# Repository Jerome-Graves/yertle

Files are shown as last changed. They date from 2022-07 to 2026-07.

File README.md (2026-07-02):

new yertle logo

# A 3D Printed Quadrupedal Robot for Locomotion Research

<p align="center" >
 
 
 
 
 
</p>

<p align="center"><b>From a hand-tuned gait to reinforcement-learned locomotion: trained on CPU (PyBullet) and GPU (Isaac Lab), deployed via a sim-to-real bridge and ROS 2.</b></p>

<br>
The robot consists of:

* 4 limbs with 3 degrees of freedom powered by hobby servos, with a leg extension of approximately 20cm.
* A 5000mah battery - 30 minutes of run time (optional). 
* A 9-axis accelerometer/gyro sensor. (optional)
* A current and voltage sensor. (optional)
* A microcontroller (ESP32s) to communicate with Hardware and sensors.
* A single-board computer (RPi4) to compute image, location, ROS and advanced controller algorithms. (optional)
* 1.8 kg

<br>
This robot was inspired by the <a href="https://grabcad.com/library/diy-quadruped-robot-1">Kangal</a>, <a href="https://spotmicroai.readthedocs.io/en/latest/">SpotMicro</a> and <a href="https://github.com/adham-elarabawy/open-quadruped">Open Quadruped</a>. The concept was to have the best parts of all designs and make it compatible with <a href="https://spotmicroai.readthedocs.io/en/latest/">SpotMicro</a> parts.
The current cost of the robot is around £250.
</br>

- - -

<br>

## Robot in action:





giphy

- - -

<br>

## Design:
Click [here](design/README.md) for 3D printer parts, assembly instructions and bill of materials.
<br><br>
Yertle is a  fusion of the leg design of <a href="https://grabcad.com/library/diy-quadruped-robot-1">Kangal</a> and the body of <a href="https://spotmicroai.readthedocs.io/en/latest/">SpotMicro</a>. As such, you can use the control software and electronics from any Kangal or derivative with this robot (with a little modification). Any Modifications for the spot micro shell will also work with this robot. And You can exchange the legs for Kangal's if you want. 
<br>
<br>
I have built a few quadruped robots and there are plenty of interesting leg mechanics to choose from. Overall The Kangal legs do have limitations. Such as their limited range in motion. But they do have the benefit of being extremely light and easy to change. This means I'm not pulling up anything heavy when I'm lifting my leg allowing the servos to be slightly faster when not under load. And I'm less worried about breaking them or putting the robot in a more extreme environment.
<br>


<br>

- - - 
<br>

## Electronics:
Click [here](design/README.md#electronics) for an electronics and wiring explanation.
<br><br>
I'm currently working on a better description of my wiring. I have soldered a custom Hat from my RPi that had all the necessary components. The robot was originally designed to use just the RPi but I found it to be unreliable as it is more complex to reset the device and more prone to corruption. As The ESP32 has WiFi I can debug the device remotely without a complex startup/shut down routine.
<br><br>
If you are familiar with wiring  <a href="https://grabcad.com/library/diy-quadruped-robot-1">Kangal</a> and the body of <a href="https://spotmicroai.readthedocs.io/en/latest/">SpotMicro</a>. You can use the same wiring.

- - -
<br>

## Software:
Click [here](software/README.md) for the software.
<br><br>
The software runs as a host/robot pair over the serial port or UDP over WiFi. The robot firmware controls all sensors and servos, computes the inverse kinematics and applies safety limits. The host side is written in Python 3: it takes the robot's sensor data, generates the motion (the hand-tuned gait in the GUI, or a learned policy from the RL pipelines) and streams it back in real time.
<br><br>
The firmware was written in C++ using Arduino IDE so you can modify it to work on a different microcontroller if you want. 
The Python Control software uses a GUI and can run on anything that has WiFi, a screen and can run Python3, including android devices(not tested).
<br><br>
There is also a ROS 2 package that runs a trained policy as a node, with a closed-loop demo and an Isaac Sim bridge; see [ros2/README.md](ros2/README.md).

- - -
<br>

## Simulation:
Click [here](simulation/README.md) for simulation tools.<br><br>
There is a simulation built into the python software. It enables you to test movement with the controller without a robot. 
<br><br>


<br><br>

Here is another simulation example from Carter James using Unity.
<br><br> 
IMAGE ALT TEXT HERE (https://www.youtube.com/watch?v=7LgCC4D3Wlk)
- - -
<br>

## Learned locomotion (reinforcement learning):
Click [here](learning/README.md) for the RL locomotion pipeline.<br><br>
Alongside the hand-tuned sinusoidal gait, Yertle now has a reinforcement-learning
environment for training a walking policy in simulation and transferring it to
the physical robot. It wraps the same URDF in a Gymnasium environment
(PyBullet backend), trains with PPO, and uses domain randomisation (mass,
friction, sensor noise, pushes) to close the sim-to-real gap. The trained
policy outputs joint targets on the existing UDP command path, so no firmware
change is needed to deploy it.

```bash
pip install -r requirements.txt -r learning/requirements-rl.txt
python -m learning.smoke_test          # check the environment
python -m learning.train --timesteps 3000000 --n-envs 8
```

- - -
<br>

## GPU locomotion with NVIDIA Isaac Lab:
Click [here](isaac_lab/README.md) for the Isaac Lab pipeline.<br><br>
The same robot is also trained on **NVIDIA Isaac Lab** (Isaac Sim 5.1 + PhysX),
the industry-standard stack for legged-robot RL. The URDF (with firmware joint
limits and actuator caps) is converted to USD and dropped into Isaac Lab's
velocity-tracking locomotion task, then trained with `rsl_rl` PPO across
**4096 parallel environments** on a single RTX GPU. A walking policy converges
in about ten minutes (~80,000 simulation steps per second). The pipeline also
includes a **rough-terrain task** (procedural terrain plus a height scanner) and
**teacher-student distillation** that removes the privileged base-velocity
observation with no loss of performance, giving a policy that runs from
on-board sensors only.

<p align="center">
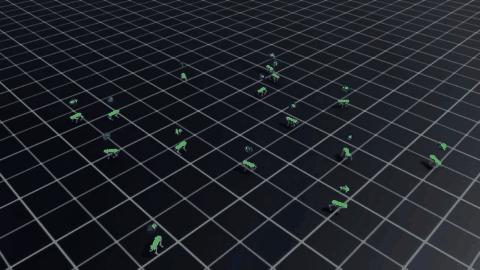
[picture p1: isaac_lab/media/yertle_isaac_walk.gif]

<br>
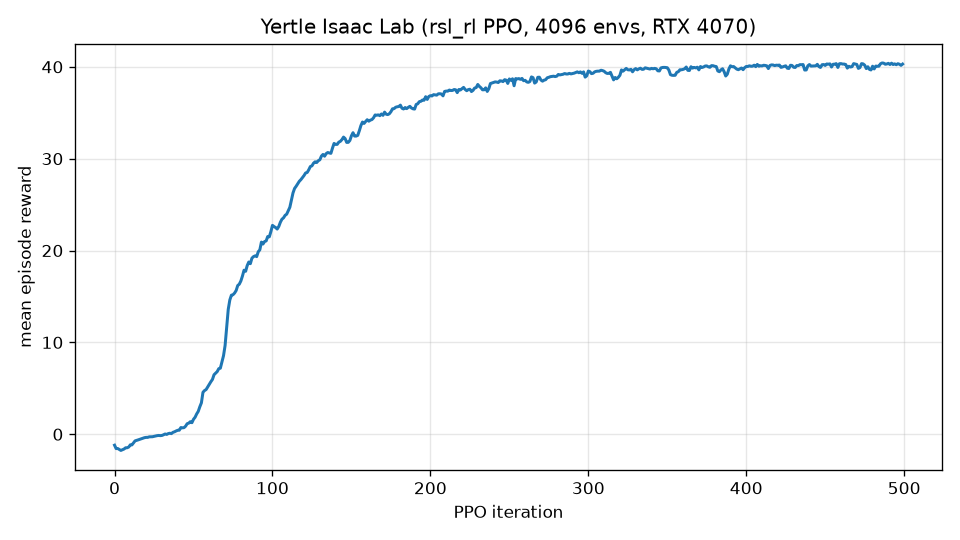
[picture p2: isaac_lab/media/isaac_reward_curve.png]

</p>

```bash
# in the Isaac Sim python env, from the repo root
python isaac_lab/train.py --task flat --headless --num_envs 4096 --max_iterations 1500
python isaac_lab/train.py --task rough --headless --num_envs 4096 --max_iterations 1000
python isaac_lab/play.py --task flat --checkpoint <model.pt> --num_envs 16 --video
python isaac_lab/distill.py --headless --teacher <model.pt>
```

- - -
<br>

## Repository structure

```
design/        3D-printed parts, assembly guide and bill of materials
simulation/    URDF model (valid inertials, firmware joint limits) and meshes
software/
    ESP32/     Robot firmware (C++, Arduino / FreeRTOS)
    yertle_ui/  Python control GUI: IK, PID balance, gait, PyBullet simulation
learning/      RL locomotion, CPU (Gymnasium + PyBullet + PPO) and sim-to-real bridge
isaac_lab/     RL locomotion, GPU (Isaac Lab + rsl_rl): flat, rough terrain,
               distillation, Isaac ROS 2 bridge
ros2/          ROS 2 package + closed-loop demo for a trained policy
paper/         Technical report (LaTeX; built PDF included)
media/         Demo montage video and GIF
requirements.txt, pyproject.toml   Python dependencies
```

- - -
<br>

## Getting started (control software)

Requires Python 3.9 or newer.

```bash
git clone https://github.com/Jerome-Graves/yertle.git
cd yertle
pip install -r requirements.txt
python software/yertle_ui/yertle_ui.py
```

On Debian/Ubuntu, tkinter is a separate system package: `sudo apt install python3-tk`.

You do not need the physical robot to try it. Launch the GUI, press **Start Simulation** to open the PyBullet digital twin, then drive it with the arrow keys.

**Building the firmware:** open `software/ESP32/firmware/firmware.ino` in the Arduino IDE with the ESP32 board package installed, along with the `FaBoPWM_PCA9685` and `MPU9250` libraries. WiFi credentials and IP addresses are set near the top of `yertle_lib.cpp`.

- - -
<br>

## Technical report

A six-page write-up of the whole project (system, both RL pipelines, results on
flat and rough terrain, distillation, deployment and ROS 2 integration, and the
engineering lessons) is in [paper/yertle_report.pdf](paper/yertle_report.pdf).

- - -
<br>

## To Do

*  Deploy the distilled policy to the physical robot and close the sim-to-real loop
*  Identify a stable measured actuator model from bench data

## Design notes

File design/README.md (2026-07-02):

new yertle logo
<p style=" display: block;margin-left: auto;margin-right: auto;text-align:center;">
    
</p>


# Table of Contents 
<p  style=" display: block;margin-left: auto;margin-right: auto;text-align:center;">
<a href="#3d-printed-parts">3D Printed Parts</a><br>
<a href="#bill-of-materials">B.O.M (Bill of Materials)</a><br>
<a href="#electronics">Electronics</a><br>
<a href="#assembly">Assembly</a><br>
</p>

- - -

<br>

# 3D Printed Parts 
Yertle can be 3D printed with PLA or ABS. You will need a printer with a build plate of at least 150x150mm. It took me roughly 2 weeks (5-10 hours a day) to print all the parts on my <b>Ender 3 Pro</b>. Most of the parts are compatible with the original SpotMicro parts.

<br>

### Shell:

| Item | Quantity | Link | Notes |
| --- | --- | --- | --- |
| Top Shell | 1 | [link](STL/Shell/Top_Shell.stl) | print in secondary colour  |
| Bottom Shell | 1 | [link](STL/Shell/Bottom_Shell.stl) |print in secondary colour |
| Front Shell | 1 | [link](STL/Shell/Front_Shell.stl) |print in secondary colour  |
| Back Shell | 1 | [link](STL/Shell/Back_Shell.stl) | print in secondary colour |

<br>

### Body Frame:
| Item | Quantity | Link | Notes |
| --- | --- | --- | --- |
| Inner Shoulder Frame | 2 | [link](STL/Frame/Inner_Shoulder_Frame.stl) |  no supports|
| Outer Shoulder Frame | 2 | [link](STL/Frame/Outer_Shoulder_Frame.stl) |  no supports|
| Upper Shoulder Frame | 2 | [link](STL/Frame/Upper_Shoulder_Frame.stl) |  no supports|
| Lower Shoulder Frame | 2 | [link](STL/Frame/Lower_Shoulder_Frame.stl) |  no supports|
| Left Servo Mount | 2 | [link](STL/Frame/Left_Servo_Mount.stl) |  no supports|
| Right Servo Mount | 2 | [link](STL/Frame/Right_Servo_Mount.stl) |  no supports|
| Servo Mount Top Bracket  | 4 | [link](STL/Frame/Servo_Mount_Top_Bracket.stl) |  no supports|
| Side Body beam | 2 | [link](STL/Frame/Side_Body_Beam.stl) |  no supports|
| Electronics Mounting Plate | 1 | [link](STL/Frame/Electronics_Mounting_Plate.stl) |  no supports|

<br>

### Legs:
| Item | Quantity | Link | Notes |
| --- | --- | --- | --- |
| Inner Tibia | 4 | [link](STL/Legs/Inner_Tibia.stl) | |
| Outer Tibia | 4 | [link](STL/Legs/Outer_Tibia.stl) | |
| Femur | 4 | [link](STL/Legs/Femur.stl) | |
| Femur Servo Connector | 4 | [link](STL/Legs/Femur_Servo_Connector.stl) | high infill|
| Left Shoulder | 2 | [link](STL/Legs/Left_Shoulder.stl) |  print in secondary colour |
| Right Shoulder | 2 | [link](STL/Legs/Right_Shoulder.stl) |  print in secondary colour |
| Short Link | 4 | [link](STL/Legs/Short_Link.stl) | |
| Long Link | 4 | [link](STL/Legs/Long_Link.stl) |  |

- - -

<br>
<br>

# Bill of Materials:
| Item | Quantity | Cost | Link | Notes |
| --- | --- | --- | --- | --- |
| PLA | 1Kg | £19 | -- | This can also be ABS or PETG. |
| SPT Servo SPT5435LV-180W 35KG | 12 | £162.36 | [link](https://uk.banggood.com/SPT-Servo-SPT5435LV-180W-35KG-Large-Torque-Waterproof-Metal-Gear-Digital-Servo-For-RC-Robot-RC-Car-p-1577514.html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) | They need to be >= 15Kg/cm.|
| M3 Screws, Nuts and washers | x100 | £10 | [link](https://amzn.eu/d/dV1QDNL) | |
| MPU9250 | 1 | £5 | [link](https://www.aliexpress.com/item/1005004573086760.html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) | optional, you can use a different IMU if needed |
| ESP32s | 1 | £5 | [link](https://www.google.com/search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) | |
| (Raspberry Pi 4B) | 1 | £50 | [link](https://www.aliexpress.com/item/1005003952938315.html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) | This is optional, The robot can use a remote device instead.  |
| PCA9685 Servo Driver | 1 | £4 | [link](https://www.aliexpress.com/item/32469378576.html) |  |
| 7.4V 2S 5000mAh 50C LiPo Battery | 1 | £30 | [link](https://amzn.eu/d/aaM0lUO) | this can be smaller if you want less weight/cost |
| SBEC 6V 20A | 1 | £20 | [link](https://hobbyking.com/en_us/yep-20a-hv-2-12s-sbec-w-selectable-voltage-output.html) | |
| Miniature Ball Bearings 5x16x5mm | 4 | £3 | [link](https://www.ebay.co.uk/itm/394185642290) | |
|  Deep Groove Ball Bearings 25x37x7mm | 4 | £9 | [link](https://www.ebay.co.uk/itm/124120979478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) |  |
|  RS PRO Miniature Ball Bearing 3x13X5mm  | 8 | £9 | [link](https://www.ebay.co.uk/itm/304258710252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) |  |
| 25T Metal Servo Circular Horn | 4 | £5 | [link](https://amzn.eu/d/hwdEX03) |  |
| 25T Metal Servo Arm Horn  | 4 | £5 | [link](https://www.amazon.co.uk/N-Aluminum-Clamping-Steering-Crawler/dp/B08V4NP2JT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) |  |
| Sleeve Bearing 3mm Bore x 5mm OD x 5mm | 32 | £15 | [link](https://amzn.eu/d/bPWGEY8) |  |
<br>

<br>
<br>

# Electronics

Yertle is controlled by an ESP-32s microcontroller and a Raspberry Pi 4 Single board computer. The robot can operate with just the ESP but will require a computer or phone with WiFi capable of running python3. The flow diagram shows the general electronic connections and wiring. 
The current and voltage sensors are optional.

Yertle Diagram flow

<br>
<br>

# Assembly

<br>

## Part1:
Connect and wire electronics to the mounting plate. You can use cable ties to hold the SBEC and battery. I normally connect the esp on top of the pi by soldering a custom Pi hat board that also mounts the IMU.



<br>

## Part2:
Construct the frame with inner servos and electronics.


<br>

## Part3:
Construct the legs.



<br>

## Part4:
Connect electronics and zero the servos (before connecting legs).



<br>

## Part5:
Connect legs and Shell.



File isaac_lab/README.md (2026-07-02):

# Yertle on Isaac Lab (GPU RL)

A second, GPU-accelerated locomotion pipeline for Yertle built on **NVIDIA Isaac
Lab** (Isaac Sim 5.1 + PhysX). It trains a velocity-tracking walking policy with
thousands of parallel environments on an RTX GPU, complementing the CPU
[PyBullet pipeline](../learning/README.md).

```
isaac_lab/
    yertle_cfg.py           Articulation config (spawns the converted USD, leg actuators)
    flat_env_cfg.py         Flat-terrain velocity task (inherits Isaac Lab's locomotion env)
    rough_env_cfg.py        Rough-terrain task (procedural terrain + height scanner)
    rsl_rl_ppo_cfg.py       PPO runner configs (flat and rough)
    distill_env_cfg.py      Distillation env (student obs group without privileged terms)
    rsl_rl_distill_cfg.py   Teacher-student distillation runner config
    train.py                Train on GPU (--task flat|rough)
    play.py                 Roll out / record a trained policy (--task flat|rough)
    distill.py              Distill the trained teacher into a deployable student
    ros2_bridge.py          Expose the Isaac simulation on ROS 2 topics (bidirectional)
```

The environment inherits Isaac Lab's proven `LocomotionVelocityRoughEnvCfg` (the
task that trains ANYmal / Unitree Go2 to walk) and swaps in the Yertle robot,
remapping body names to Yertle's (`base_link`, feet = `*_shin`).

## Prerequisites

Isaac Sim needs Python 3.10/3.11 and an NVIDIA RTX GPU. Create a dedicated
Python 3.11 virtual environment (referred to as `<isaac_venv>` below) and
install per Isaac Lab's pip instructions:

```bash
pip install -U torch==2.7.0 torchvision==0.22.0 --index-url https://download.pytorch.org/whl/cu128
pip install "isaaclab[isaacsim,all]==2.3.2.post1" --extra-index-url https://pypi.nvidia.com
```

## 1. Convert the robot model (URDF -> USD)

```bash
python IsaacLab/scripts/tools/convert_urdf.py \
    simulation/yertle.urdf simulation/usd/yertle.usd --merge-joints --headless
```

This is already done; the USD lives in `simulation/usd/`.

## 2. Train (GPU)

Run from the repo root with the Isaac Sim python and the EULA accepted. Run the
scripts as plain files (not `-m`): on Windows, importing heavy libraries before
the Kit app launches is what avoids the DLL-conflict crash, and the scripts
handle that ordering themselves.

```bat
set OMNI_KIT_ACCEPT_EULA=YES
<isaac_venv>\Scripts\python.exe isaac_lab\train.py --task flat --headless --num_envs 4096 --max_iterations 1500
<isaac_venv>\Scripts\python.exe isaac_lab\train.py --task rough --headless --num_envs 4096 --max_iterations 1000
```

Logs and checkpoints: `isaac_lab/runs/<experiment>/<timestamp>/`. Watch with
`tensorboard --logdir isaac_lab/runs`.

## 3. Play / record

```bat
<isaac_venv>\Scripts\python.exe isaac_lab\play.py --task flat --checkpoint <path> --num_envs 16 --video
```

## 4. Distill to a deployable policy

The flat policy observes the base linear velocity, which the real robot cannot
measure. Distillation trains a student from a deployable observation set (no
base linear velocity, no height scan) to imitate the trained teacher:

```bat
<isaac_venv>\Scripts\python.exe isaac_lab\distill.py --headless --teacher isaac_lab\runs\yertle_flat\<run>\model_1499.pt
```

Result on this robot: student mean reward 40.4 against the teacher's 40.5, with
an imitation loss of about 1e-3.

## 5. ROS 2 bridge

`ros2_bridge.py` publishes `/joint_states` and `/clock` and subscribes to
`/joint_command`, exposing the GPU simulation to any ROS 2 stack. Validated
bidirectionally; see [ros2/README.md](../ros2/README.md) for the demo and the
Windows setup notes.

## Notes

- The default standing pose and actuator gains in `yertle_cfg.py` are starting
  points carried over from the PyBullet env; tune if the robot spawns collapsed.
- The URDF now carries firmware-derived joint limits (revolute joints) and the
  actuator enforces effort/velocity caps, so learned behavior stays within what
  the hardware can execute. An explicit DC-motor actuator model was evaluated
  and rejected as underdamped at these gains (see the comment in
  `yertle_cfg.py` and the technical report).
- A quick model sanity check after any URDF/actuator change: command the
  standing pose with zero action and confirm the base height holds steady.

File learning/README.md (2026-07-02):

# Learned locomotion for Yertle

Reinforcement-learning pipeline that replaces the hand-tuned sinusoidal gait
with a **policy trained in simulation** and intended for **sim-to-real**
transfer onto the physical robot.

The environment reuses the existing `simulation/yertle.urdf`, so the learned
controller drives the same 12-DOF machine the rest of the repository builds.

```
learning/
    yertle_env.py         Gymnasium environment (PyBullet backend)
    train.py              PPO training (stable-baselines3)
    enjoy.py              Roll out / render a trained policy
    deploy.py             Sim-to-real bridge (see also ../ros2)
    record_video.py       Save an mp4/gif of a trained policy
    plot_progress.py      Reward curve PNG from a training log
    smoke_test.py         Fast env check, no RL deps required
    requirements-rl.txt   RL dependencies (gymnasium, sb3, torch, ...)
```

## Install

```bash
pip install -r requirements.txt -r learning/requirements-rl.txt
```

`smoke_test.py` only needs `pybullet`, `gymnasium` and `numpy` (already in the
base `requirements.txt`), so you can check the environment before pulling in
Torch.

## Quick start

```bash
# 1. Sanity-check the environment (random actions, a few seconds)
python -m learning.smoke_test

# 2. Short training smoke run
python -m learning.train --timesteps 20000 --n-envs 2

# 3. A real run (minutes-to-hours depending on hardware)
python -m learning.train --timesteps 3000000 --n-envs 8

# 4. Watch the result
python -m learning.enjoy --policy learning/runs/ppo_yertle/policy.zip

# 5. Produce demo artifacts
python -m learning.record_video --policy learning/runs/ppo_yertle/policy.zip --seconds 8
python -m learning.plot_progress --log learning/runs/train_ppo_yertle.log
```

TensorBoard: `tensorboard --logdir learning/runs`.

## Environment design

**Action** (12): joint-angle residuals around a fixed standing pose, tracked by
a position controller. This matches how the real robot is commanded (joint
angles over WiFi/serial), which keeps the sim-to-real gap small.

**Observation** (48): base linear velocity, base angular velocity, projected
gravity (an IMU-style "which way is down" signal), the velocity command, and
joint positions / velocities / previous action.

**Reward**: track a commanded body velocity (forward, lateral, yaw) while
staying upright and at height, with penalties on energy, action rate,
orientation and falling.

**Physics sanitation.** The shipped URDF was authored for visualisation and its
inertia tensors are not physically valid, so the raw model diverges when
simulated freely. On load the environment overrides each link's inertia with a
stable estimate from its mass and sets foot friction. Turning a display model
into a trainable dynamics model is part of the work here.

**Domain randomisation** (per episode): base mass, foot friction, observation
noise and random pushes. This is the main lever for surviving transfer to
hardware.

## Sim-to-real plan

The policy is a small MLP, so deployment is light:

1. Export the trained weights (the residual-around-stance action design makes
   the mapping to servo angles direct).
2. Run inference at the control rate on the Raspberry Pi (or a laptop) using
   the IMU + commanded joint state to build the observation.
3. Stream the resulting joint targets to the ESP32 over the existing UDP path
   (`f`/`a` command strings in `software/ESP32/firmware`).

The privileged observation term (base linear velocity) is handled by
teacher-student distillation in the GPU pipeline
([isaac_lab/distill.py](../isaac_lab/distill.py)): the student policy matches
the teacher with that term removed, so deployment needs only on-board signals.

## Status

Complete and validated end to end: the environment trains, and the included
full run (3M steps) produced a walking policy that tracks commanded forward
speeds of about 0.2 m/s. The same policy also drives the robot over live ROS 2
topics in the closed-loop demo (`ros2/demo_ros2_loop.py`). For a faster, more
polished gait, see the GPU pipeline in [isaac_lab/](../isaac_lab/README.md),
which trains in minutes and adds rough terrain and distillation.

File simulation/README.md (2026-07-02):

new yertle logo

# Simulation
 
 



<!--
# Table of Contents 
<p  style=" display: block;margin-left: auto;margin-right: auto;text-align:center;">
<a href="#wifi">WiFi</a><br>
<a href="#Robot Firmware">Firmware</a><br>
<a href="#Control Software">Control Software</a><br>
<a href="#ros">ROS</a><br>

</p>
-->

- - -
<br><br>
The robot model is the URDF file [yertle.urdf](yertle.urdf). It is
simulation-ready: the inertia tensors are physically valid, the twelve leg
joints are revolute with firmware-derived limits, and the actuators carry
effort and velocity caps, so the same model works in PyBullet and in
PhysX-based simulators.

For NVIDIA Isaac Sim / Isaac Lab, convert it to USD with Isaac Lab's importer
(the generated `usd/` directory is regenerable and not committed):

```
python IsaacLab/scripts/tools/convert_urdf.py simulation/yertle.urdf simulation/usd/yertle.usd --merge-joints --headless
```
<br>

There is a pyBullet simulation in the python control software, and the RL
pipelines ([learning/](../learning/README.md),
[isaac_lab/](../isaac_lab/README.md)) build their training environments from
this same model.
<br><br>

<br><br>
It creates a digital twin of the robot. You can control it with the UI. To move the robot around using the Keyboard direction keys. 
<br><br>

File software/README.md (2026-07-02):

new yertle logo
<p>
 
 
 
</p>


# Table of Contents 
<p  style=" display: block;margin-left: auto;margin-right: auto;text-align:center;">
<a href="#wifi">WiFi</a><br>
<a href="#Robot Firmware">Firmware</a><br>
<a href="#Control Software">Control Software</a><br>
<a href="#ros">ROS</a><br>

</p>

- - -
<br><br>
There are 2 options for controlling the robot. You can run The python GUI script from a remote device and connect to the robot via WiFi (recommended) or use a remote desktop application to run the script from the RPi.
<br><br>

# WiFi

There are a few references to IP addresses in the code. You will have to modify them in the python and the .ino file.  I am working on making this easier.
<br><br>
The robot will want to connect to WiFi when it starts.
The default login details are: <br>
* SSID : <b>dog-net</b>

* PASSWORD: <b>dognet123</b>

You can change these near the top of the <b>yertle_lib.cpp</b> file.
<br><br>

</p>

- - -

<br>

# Firmware
This was written in <b>C++</b> using the <b>Arduino IDE</b>. It uses <b>FreeRtos</b> to separate tasks to different cores of the ESP32.
One task deals with WiFi and serial communication, while the other deals with I2C communication and inverse kinematics calculations. [Link](ESP32/firmware/firmware.ino)

- - -

<br>

# Control Software
This was written in <b>Python3</b> and uses the <b>tkinter</b> library to generate a GUI to control the robot. It connects to the robot through either <b>Wifi</b> or <b>serial</b> communication. The robot sends sensor information and the control software generates the feet's position and sends it back to the robot in real-time.



## Configuring IMU

The IMU needs to be initially calibrated. These settings are saved in an <b>.ini</b> and reused when the robot is restarted.
- - -
<br>

## Zeroing servos
You can use this GUI to Zero servos before fully constructing robot.
* Use the servo control tab bo visual center servos 
* Press the Get PWM button to get the current PWM values and use these in <b>.ino</b> file to set <b>servo offsets</b>.

<br>

# ROS 2
Done. A ROS 2 package (`ros2/yertle_rl`) runs a trained locomotion policy as a
node (subscribes `/cmd_vel` and `/imu/data`, publishes 12 joint targets), with a
closed-loop walking demo over live topics and a bidirectional Isaac Sim bridge.
See [ros2/README.md](../ros2/README.md).
- - -

<br>

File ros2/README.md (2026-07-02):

# ROS 2 integration

A ROS 2 node that runs the learned locomotion policy on Yertle.

```
ros2/
    yertle_rl/                 ament_python package
        yertle_rl/policy_node.py   the node (thin wrapper over learning/deploy.py)
        package.xml, setup.py      package metadata
```

## What the node does

`policy_node` subscribes to a velocity command and IMU (and optionally joint
feedback), runs the trained policy at a fixed control rate, and publishes 12
joint targets:

| Direction | Topic | Type |
|---|---|---|
| sub | `/cmd_vel` | `geometry_msgs/Twist` |
| sub | `/imu/data` | `sensor_msgs/Imu` |
| sub | `/joint_states` (optional) | `sensor_msgs/JointState` |
| pub | `/joint_commands` | `std_msgs/Float64MultiArray` (12 targets, rad) |

The heavy lifting (observation assembly, policy inference, joint limiting) lives
in [`learning/deploy.py`](../learning/deploy.py), which is validated by the
simulation self-check (`python -m learning.deploy --check`). The node is a thin
ROS wrapper around that same tested core.

## Status

Built and run on **ROS 2 Humble**: the package compiles with `colcon`, and the
node runs live — publishing a `/cmd_vel` and an `/imu` produces `/joint_commands`
(12 joint targets) from the policy. It was validated on Windows with no WSL, via
RoboStack (ROS 2 as conda packages), which is the quickest way to run it here.

**Closed-loop demo.** `demo_ros2_loop.py` runs the full control loop over ROS 2
topics: a PyBullet simulation node publishes `/joint_states` and `/imu/data` and
applies `/joint_commands`, while `policy_node` runs the trained policy against a
`/cmd_vel` command. With the trained PyBullet policy the robot walks
(~0.5 m of base travel in 8 s at a 0.25 m/s command):

```bash
conda run -n ros2 python ros2/demo_ros2_loop.py --policy learning/runs/ppo_walk2/policy.zip
```

**Isaac Sim bridge (validated, bidirectional).** `isaac_lab/ros2_bridge.py`
exposes the GPU simulation on ROS 2 topics through Isaac's
`isaacsim.ros2.bridge` OmniGraph extension: it publishes `/joint_states` and
`/clock` and subscribes to `/joint_command` (sensor_msgs/JointState). This was
verified end to end across two separate ROS 2 installations: the RoboStack env
receives all 12 Yertle joints on `/joint_states`, and commanding
`/joint_command` from RoboStack moves the joints in Isaac (thigh commanded to
-1.2 rad, tracked exactly). Two Windows notes, handled by the launcher: the
bridge needs `ROS_DISTRO=humble` and Isaac's bundled
`isaacsim.ros2.bridge\humble\lib` on `PATH` before startup, and the sim loop
must step with an app update (`sim.step(render=True)`) or the OmniGraph
publishers never tick.

## Build and run — Linux (Ubuntu, ROS 2 Humble/Jazzy)

```bash
# from a sourced ROS 2 workspace
mkdir -p ~/yertle_ws/src && cd ~/yertle_ws/src
ln -s /path/to/yertle/ros2/yertle_rl .
cd ~/yertle_ws
colcon build --packages-select yertle_rl
source install/setup.bash

# the node imports the repo's `learning` package; put the repo root on PYTHONPATH
PYTHONPATH=/path/to/yertle ros2 run yertle_rl policy_node \
    --ros-args -p policy_path:=/path/to/policy.zip
```

## Build and run — Windows (no WSL, via RoboStack)

```bat
:: install Miniforge, then create a ROS 2 env
conda create -y -n ros2 -c conda-forge -c robostack-staging ros-humble-ros-base colcon-common-extensions
conda run -n ros2 pip install pybullet gymnasium

:: build (keep outputs outside the repo)
cd yertle\ros2
conda run -n ros2 colcon build --base-paths . --build-base %USERPROFILE%\ros_ws\build --install-base %USERPROFILE%\ros_ws\install
```

Before building, set your maintainer email in `package.xml` and `setup.py`
(currently a placeholder). The node runs with no `policy_path` too, in which
case it outputs the standing pose (handy for a plumbing check).

## Wiring it to the robot

`/joint_commands` (target joint angles in radians) can be consumed by either:

* a `ros2_control` forward position controller in a Gazebo/RViz simulation, or
* a small relay that reuses `learning.deploy.servo_command_string` to forward
  the targets to the ESP32 firmware over UDP.

The IMU and joint feedback plumbing mirrors the sim-to-real notes in
[`learning/README.md`](../learning/README.md): base linear velocity is a
privileged term and is zero-filled on hardware.

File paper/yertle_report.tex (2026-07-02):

\documentclass[11pt]{article}

% Build with XeLaTeX + Biber (see build.ps1).
\usepackage{fontspec}
\usepackage[a4paper,margin=25mm]{geometry}
\usepackage{graphicx}
\usepackage{booktabs}
\usepackage{amsmath}
\usepackage{siunitx}
\usepackage{xcolor}
\usepackage{caption}
\usepackage[colorlinks=true,linkcolor=black,citecolor=blue,urlcolor=blue]{hyperref}
\usepackage[backend=biber,style=numeric,sorting=none]{biblatex}
\addbibresource{references.bib}

\captionsetup{font=small,labelfont=bf}
\graphicspath{{figures/}}

\title{\textbf{Yertle: Learned Locomotion for a Low-Cost 3D-Printed Quadruped}\\
\large From a Hand-Tuned Gait to Reinforcement Learning and Sim-to-Real}
\author{Jerome Graves}
\date{2026}

\begin{document}
\maketitle

\begin{abstract}
\noindent
Yertle is an open-source, 3D-printed, twelve degree-of-freedom quadruped built
from hobby servos at a hardware cost of around \pounds 250. This report describes
its progression from a hand-tuned sinusoidal gait to learned locomotion trained
with deep reinforcement learning, together with a path to deployment on the
physical robot. Two independent training pipelines are presented: a CPU pipeline
using PyBullet and Proximal Policy Optimization, and a GPU pipeline using NVIDIA
Isaac Lab with thousands of parallel environments. The Isaac Lab pipeline learns
a velocity-tracking walking policy in about ten minutes on a single consumer GPU,
reaching full-length episodes (the robot does not fall) while tracking commanded
body velocities. A sim-to-real deployment bridge and a ROS 2 node are described
that turn a trained policy into joint commands for the on-board microcontroller.
The report also documents the practical engineering that such a project requires,
including physics-model repair, reward shaping, and a set of Windows-specific
issues encountered when running the simulators.
\end{abstract}

\section{Introduction}
Legged locomotion has moved decisively toward learning-based control. Policies
trained in simulation and transferred to hardware now walk, run, and recover on
real quadrupeds \cite{hwangbo2019anymal}, and the availability of massively
parallel GPU simulation has reduced training time from days to
minutes \cite{rudin2022minutes}. Most demonstrations, however, use expensive
research platforms. This work applies the same modern stack to \emph{Yertle}, a
cheap, printable quadruped, and takes it end to end: from a mechanism and
firmware through two reinforcement-learning pipelines to a deployable controller
and a ROS 2 interface.

The contributions are practical rather than novel in method. They are: (i) a
clean, reproducible reinforcement-learning environment for a low-cost quadruped,
provided in both a CPU (PyBullet) and a GPU (Isaac Lab) form; (ii) a trained
velocity-tracking walking policy and the artifacts to reproduce it; (iii) a
sim-to-real bridge and a ROS 2 node that connect the learned policy to the
existing firmware; and (iv) an honest account of the engineering obstacles, which
are usually omitted from polished results but dominate the real effort.

\section{System Overview}
Yertle consists of four legs, each with three degrees of freedom driven by hobby
servos, giving a leg extension of roughly \SI{20}{\centi\meter} and a total mass
near \SI{1.8}{\kilogram}. An ESP32 microcontroller running FreeRTOS handles the
servo bus (through a PCA9685 driver), reads a nine-axis inertial measurement
unit, and communicates over WiFi or serial. One core computes inverse kinematics
and drives the servos; the other handles communication. A host computer sends
either joint angles or Cartesian foot targets, and the firmware executes them.
The original control software is a Python GUI that generates a sinusoidal trot by
hand. The work described here replaces that hand-tuned gait with a learned policy.

\section{Simulation Model}
Both pipelines share the same kinematic description, a URDF exported from the CAD
model. Preparing this model for physics simulation required two fixes that are
representative of the practical work involved.

\paragraph{Inertia.} The exported URDF specified physically invalid inertia
tensors: zero inertia on the base link and, on the leg links, off-diagonal terms
equal to the diagonal terms. A valid rigid-body inertia tensor must be symmetric
positive-definite. PyBullet tolerates the invalid values by silently
recomputing, but the PhysX engine used by Isaac Lab rejects them for articulated
bodies. Each tensor was replaced with a stable, mass-scaled diagonal estimate.

\paragraph{Mesh naming.} Four mesh files contained spaces in their names. This is
harmless for PyBullet but illegal in the prim-path syntax used by Universal Scene
Description (USD), so the conversion to USD failed until the files were renamed.

For the GPU pipeline the corrected URDF is converted to USD with Isaac Lab's
importer, merging the fixed base joint and producing an articulation with a
\texttt{base\_link} root and twelve revolute joints.

\section{Method}
\subsection{Reinforcement-learning formulation}
Locomotion is posed as velocity-command tracking. At each control step the policy
observes the base linear and angular velocity, a projected-gravity vector (which
is an inertial-measurement-style estimate of the down direction), the commanded
body velocity, the joint positions and velocities, and the previous action. The
action is a set of twelve target joint angles, applied as offsets around a fixed
standing pose and tracked by a position controller. This choice mirrors the real
robot, which is commanded with joint angles, and keeps the sim-to-real gap small.
The reward rewards tracking of the commanded planar and yaw velocities while
penalizing falling, energy use, action rate, and body tilt.

\subsection{CPU pipeline: PyBullet and PPO}
The first pipeline wraps the URDF in a Gymnasium \cite{towers2023gymnasium}
environment with a PyBullet \cite{coumans2021pybullet} backend and trains with
Proximal Policy Optimization \cite{schulman2017ppo} using
Stable-Baselines3 \cite{raffin2021sb3}. Domain randomization over base mass, foot
friction, sensor noise, and random pushes \cite{tobin2017domainrand} is applied
per episode to encourage transferable behavior. This pipeline runs on any
machine without a GPU and is intended as a portable, reproducible reference.

A useful lesson emerged here. An early reward function drove the policy to a
degenerate optimum in which it stood perfectly still: the survival and stability
terms, combined with a forgiving velocity-tracking kernel and command ranges that
included near-zero speeds, made standing near-optimal. The fix was to add a direct
forward-progress term, sharpen the tracking kernel, require a non-trivial
commanded speed, and add an entropy bonus for exploration. This is a
representative example of reward shaping and of the value of \emph{evaluating}
a policy rather than trusting the reward curve alone.

\subsection{GPU pipeline: Isaac Lab and rsl\_rl}
The second pipeline uses NVIDIA Isaac Lab \cite{mittal2023orbit}, built on Isaac
Sim and the PhysX engine, which simulates thousands of environments in parallel on
a single GPU \cite{makoviychuk2021isaacgym}. The Yertle articulation is dropped
into Isaac Lab's velocity-tracking locomotion task, the same task used to train
research quadrupeds, with body names remapped to Yertle's and terrain and command
ranges scaled for a small robot. Training uses the \texttt{rsl\_rl} implementation
of PPO \cite{rudin2022minutes}. A flat-ground task and a rough-terrain task (which
adds procedurally generated terrain and a height scanner) are both provided.

\section{Results}
The GPU pipeline was trained on a single NVIDIA GeForce RTX 4070 with 4096
parallel environments. Training throughput was approximately 80{,}000 simulation
steps per second, roughly two orders of magnitude faster than the single-process
CPU pipeline. A walking policy converged in about ten minutes.
Figure~\ref{fig:isaac_curve} shows the learning curve: mean episode reward rises
from near zero and plateaus after a few hundred iterations. At convergence the
mean episode length reaches its maximum, meaning the robot remains upright for the
full episode across all environments while tracking commanded velocities.
Figure~\ref{fig:isaac_walk} shows a frame from the trained policy driving a set of
robots in parallel.

\begin{figure}[t]
\centering
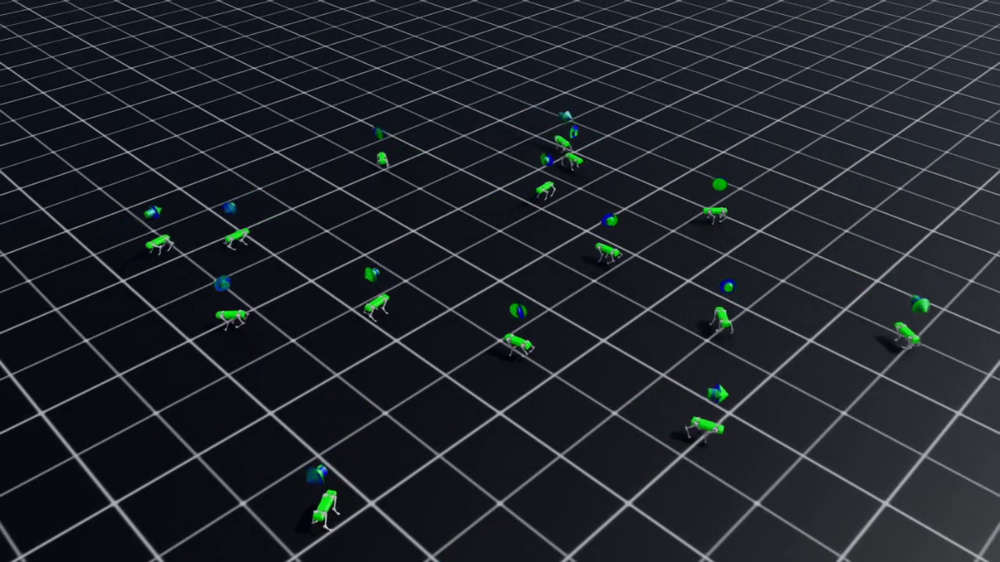
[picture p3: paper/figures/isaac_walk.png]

\caption{Trained Isaac Lab policy driving multiple Yertle robots in parallel.
Each robot tracks its own commanded velocity.}
\label{fig:isaac_walk}
\end{figure}

\begin{figure}[t]
\centering

\caption{Isaac Lab (rsl\_rl PPO, 4096 environments, RTX 4070) mean episode reward
against training iteration. The policy converges in a few hundred iterations,
about ten minutes of wall-clock time.}
\label{fig:isaac_curve}
\end{figure}

The CPU pipeline, trained from scratch on the same reward, is slower and noisier
but reaches a comparable outcome (Figure~\ref{fig:pybullet_curve}): the resulting
policy walks, tracking commanded forward speeds of around
\SI{0.2}{\meter\per\second}. Its value is as a dependency-light, GPU-free
reference and as the vehicle for the sim-to-real bridge described next.

\begin{figure}[t]
\centering
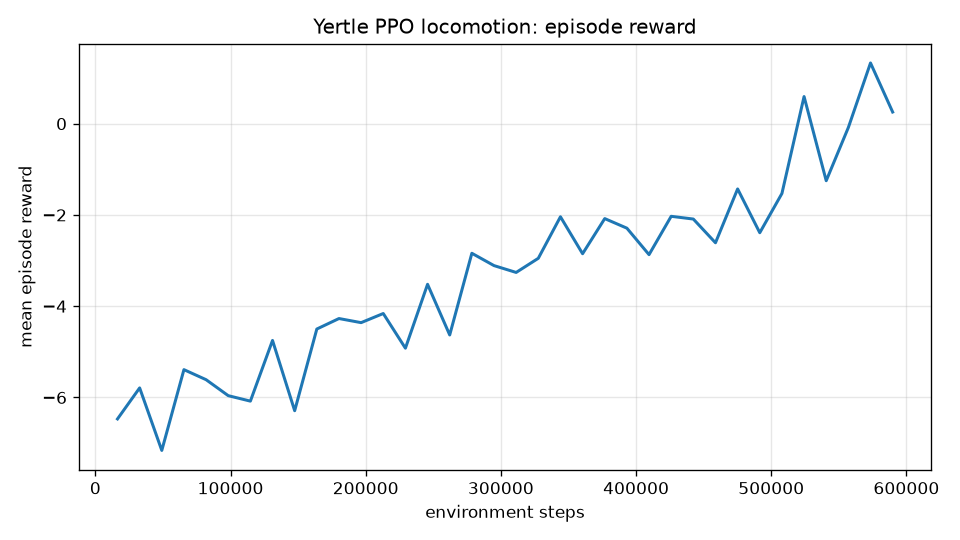
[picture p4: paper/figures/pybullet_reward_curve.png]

\caption{CPU pipeline (PyBullet, PPO) mean episode reward against environment
steps, showing the same qualitative convergence at far lower throughput.}
\label{fig:pybullet_curve}
\end{figure}

\paragraph{Rough terrain.} The GPU pipeline was also trained on a rough-terrain
task that adds procedurally generated terrain and a height scanner to the
observation. The policy learns to walk over blocks and slopes while keeping the
robot upright for nearly the full episode (Figure~\ref{fig:isaac_rough}),
demonstrating that the same setup extends to non-flat ground with only a change of
task configuration.

\paragraph{Teacher-student distillation.} The flat policy observes the base
linear velocity, which is available in simulation but not measurable on the
robot. To remove this privileged term, the trained policy was used as a frozen
teacher and a student network was trained by behavior imitation from a
deployable observation set (the same observation minus base linear velocity).
After 300 distillation iterations the student reaches a mean episode reward of
40.4 against the teacher's 40.5, with a mean imitation loss of about
$10^{-3}$: walking performance is preserved without the privileged signal, so
the deployed controller needs only the on-board inertial and joint information.

\begin{figure}[t]
\centering
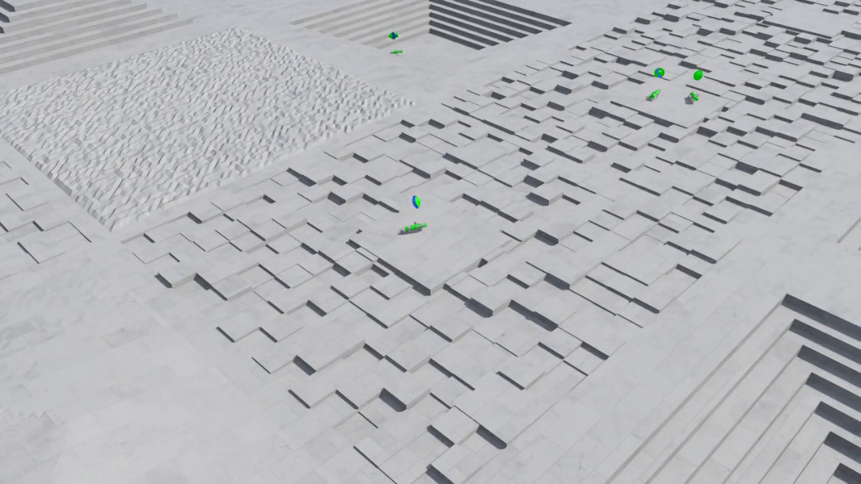
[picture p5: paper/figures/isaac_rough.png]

\caption{Rough-terrain policy: Yertle robots trained in Isaac Lab walking across
procedurally generated terrain.}
\label{fig:isaac_rough}
\end{figure}

\section{Deployment}
\subsection{Sim-to-real bridge}
A deployment module runs a trained policy at the control rate and converts its
output into firmware joint commands. The observation builder and policy
controller mirror the training environment exactly, and a joint-mapping layer
translates policy targets into the servo convention. Two interfaces are provided:
a PyBullet interface that closes the loop in simulation for validation, and a UDP
interface that streams commands to the ESP32 over the existing protocol. One term
in the observation, the base linear velocity, is available in simulation but not
on the robot; the distilled student policy described above removes it, so the
deployed controller runs from measurable signals only.

\subsection{ROS 2 integration}
A ROS 2 node wraps the same tested deployment core. It subscribes to a velocity
command and an inertial-measurement topic and publishes joint targets, so the
learned controller can be driven from the standard ROS 2 tooling and connected to
a \texttt{ros2\_control} stack or a hardware relay. The node was built with
\texttt{colcon} and run on ROS 2 Humble, and the full control loop was
demonstrated over live topics: a simulation node publishes joint states and
inertial data, the policy node tracks a commanded velocity, and the robot walks.

In addition, the GPU simulation itself was exposed on ROS 2. Through Isaac Sim's
ROS 2 bridge (an OmniGraph action graph), the simulator publishes
\texttt{/joint\_states} and a clock and accepts \texttt{/joint\_command}. This
was verified bidirectionally across two independent ROS 2 installations: an
external ROS 2 environment receives all twelve joint states and, publishing a
joint command, moves the simulated robot, whose tracked position is read back
over the same topics.

\section{Engineering Notes}
Beyond the model repair and reward shaping already described, running the GPU
simulator on a Windows workstation required resolving several dynamic-library
conflicts: the deep-learning runtime and the simulator each load their own math
and OpenMP libraries, and the import order had to be controlled to avoid a hard
crash. Long training runs were launched as detached processes so they survive an
interrupted session.

Two further failure modes are worth recording because each looked like a
learning problem and was not. First, when smoothness penalties (action rate,
joint acceleration, body wobble) were increased to improve gait quality, the
per-step reward went negative; since falling terminates the episode, the optimal
policy became falling immediately to stop accumulating penalty, and mean episode
length collapsed from 1000 steps to about 16. Penalty weights must keep the
per-step reward of useful behavior positive. Second, replacing the implicit
position drive with an explicit DC-motor actuator model, nominally closer to a
real servo, made the robot unable to hold its own stance: at hobby-servo gains
the explicitly applied torque is underdamped, and the torque-speed curve removes
torque exactly when recovery velocity is highest, so the legs oscillate against
their joint limits. A zero-action diagnostic (command the standing pose, watch
base height) isolated both problems in minutes, where staring at training curves
had not. These issues are mundane individually but, collectively, are where most
of the real time is spent, and they are the reason the reproducibility scripts in
the repository are worth as much as the environment code.

\section{Conclusion and Future Work}
Yertle demonstrates that the modern learned-locomotion stack is accessible on a
cheap, printable quadruped and a consumer GPU. A velocity-tracking walking policy
is trained in minutes; the privileged observation is removed by teacher-student
distillation with no loss of performance; and the controller is connected to the
robot's firmware through a deployment bridge, a ROS 2 node running the full loop
over live topics, and a bidirectional Isaac Sim ROS 2 bridge. The simulation
model carries the firmware's joint limits and actuator effort and velocity caps,
which constrain learned behavior to what the hardware can execute. Immediate
future work is to close the sim-to-real loop on the physical robot and to
identify a stable measured actuator model. The code, trained artifacts, and
reproduction scripts are available in the project repository.

\printbibliography

\end{document}

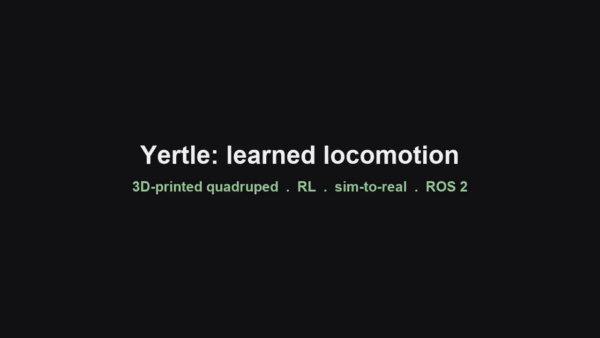
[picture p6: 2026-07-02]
media/yertle_demo.gif

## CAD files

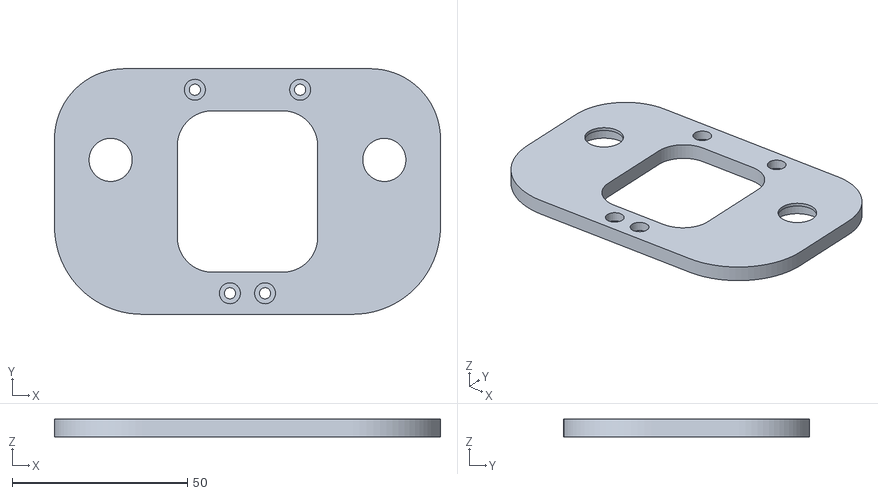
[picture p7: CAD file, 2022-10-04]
design/STL/Frame/Outer_Shoulder_Frame.stl
110.0 x 70.0 x 5.00

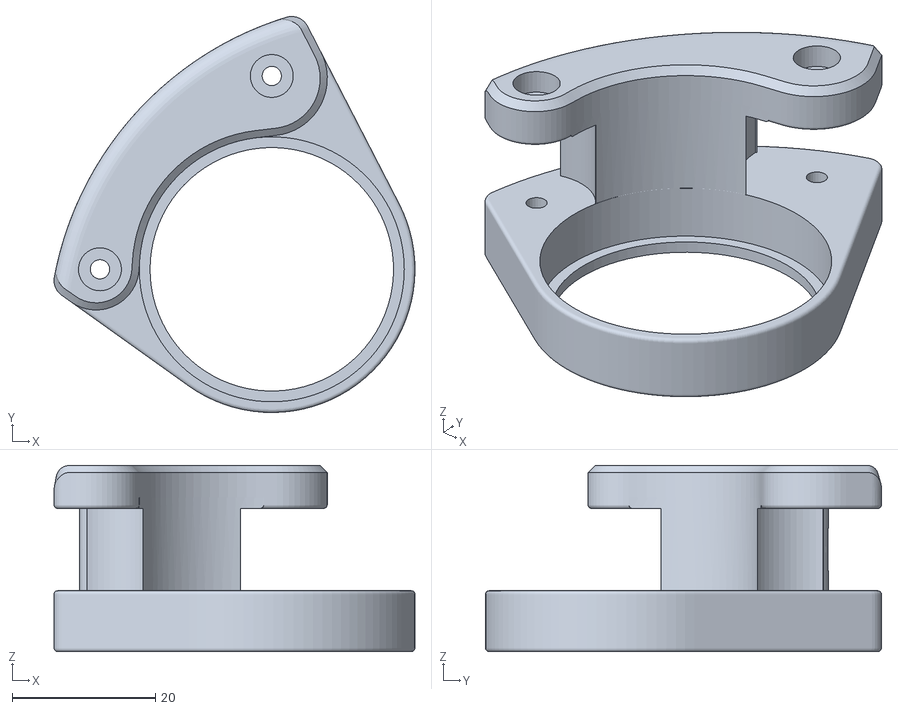
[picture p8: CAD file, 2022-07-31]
design/STL/Legs/Left_Shoulder.stl
50.4 x 55.3 x 26.0

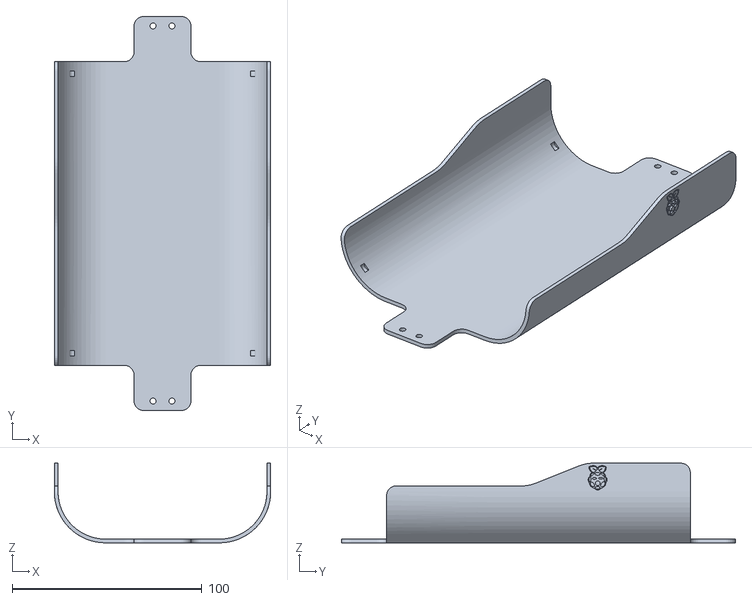
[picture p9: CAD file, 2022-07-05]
design/STL/Shell/Bottom_Shell.stl
114.0 x 207.5 x 42.0

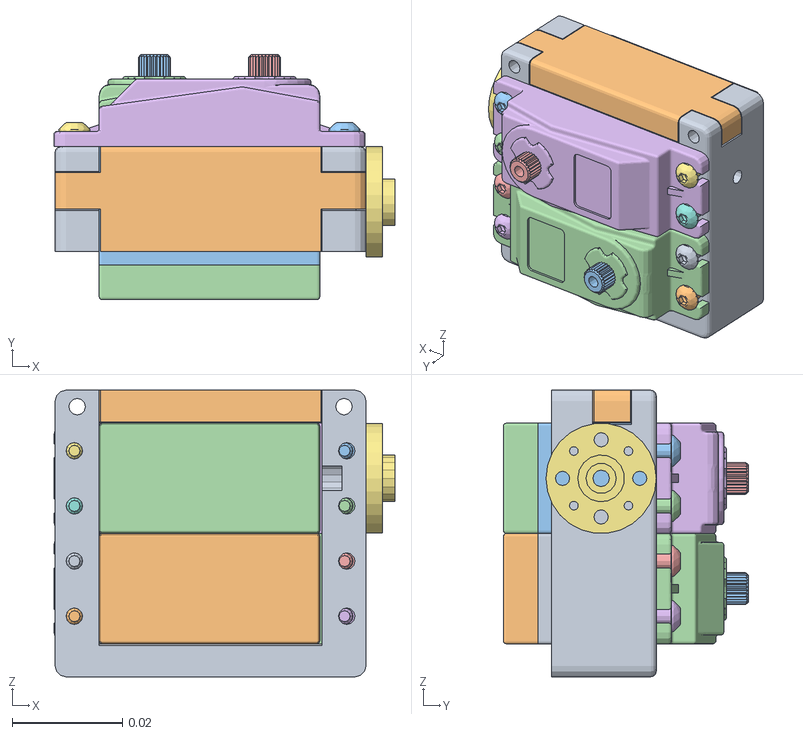
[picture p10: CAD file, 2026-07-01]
simulation/meshes/rf_shoulder.obj
0.0618 x 0.0445 x 0.052

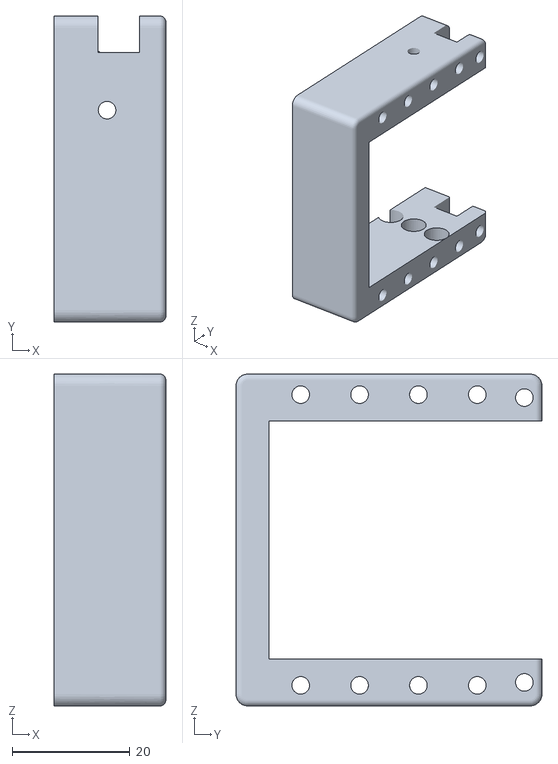
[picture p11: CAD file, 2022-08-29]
design/STL/Frame/Left_Servo_Mount.stl
19.0 x 52.0 x 56.4

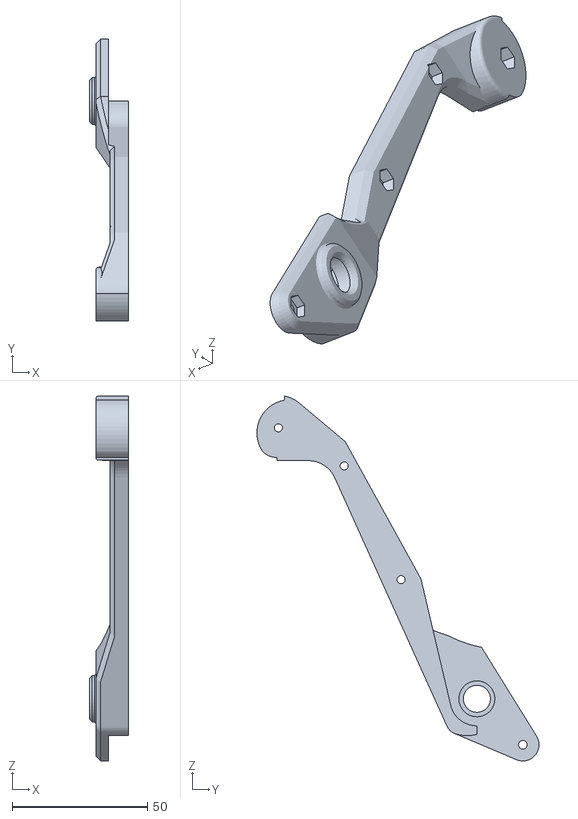
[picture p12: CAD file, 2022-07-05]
design/STL/Legs/Inner_Tibia.stl
14.4 x 104.2 x 134.8

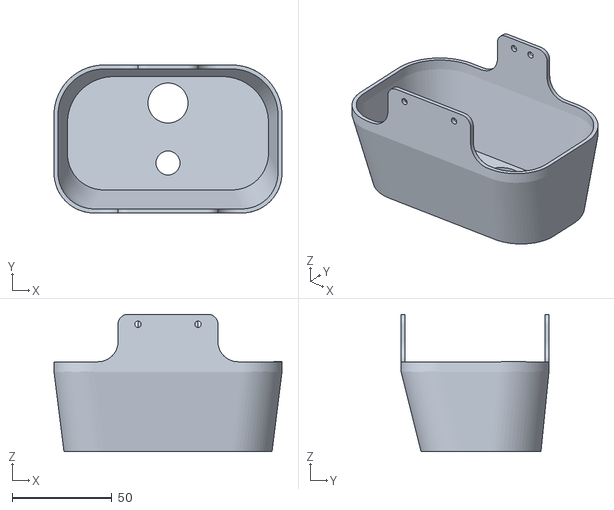
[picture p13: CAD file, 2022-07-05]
design/STL/Shell/Back_Shell.stl
114.0 x 74.0 x 68.8

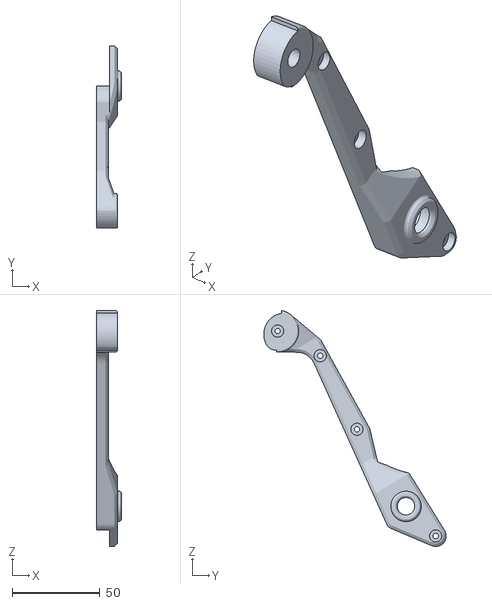
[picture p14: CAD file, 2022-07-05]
design/STL/Legs/Outer_Tibia.stl
14.4 x 104.2 x 134.8

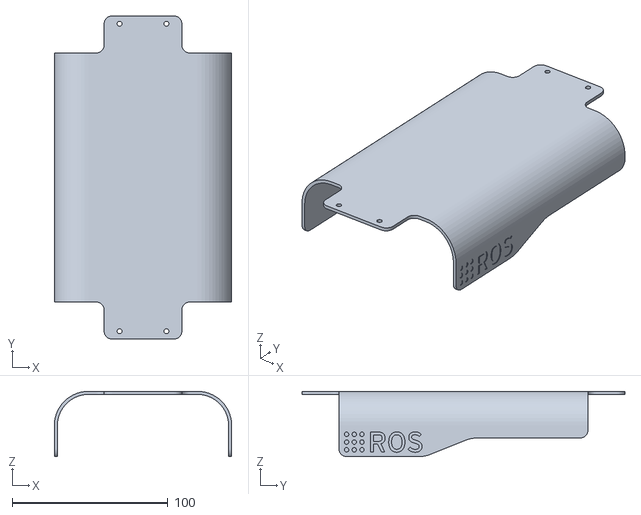
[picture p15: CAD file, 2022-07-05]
design/STL/Shell/Top_Shell.stl
114.0 x 207.5 x 42.0

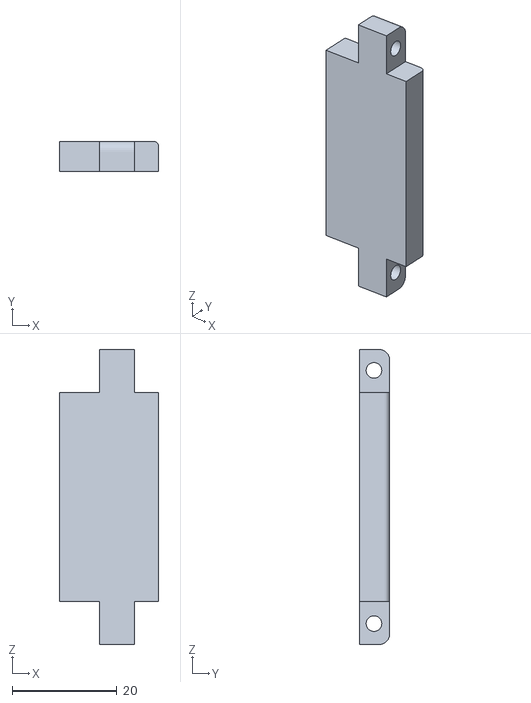
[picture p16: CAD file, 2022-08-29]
design/STL/Frame/Servo_Mount_Top_Bracket.stl
19.0 x 5.80 x 56.4

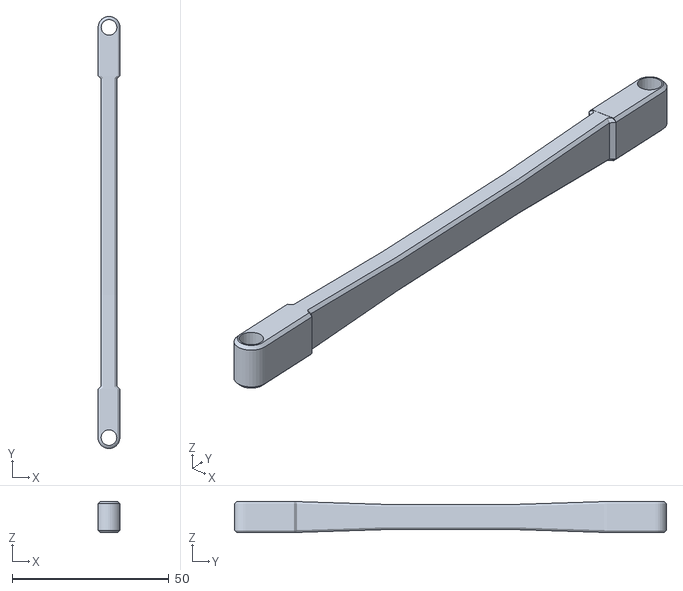
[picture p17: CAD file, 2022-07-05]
design/STL/Legs/Long_Link.stl
7.03 x 138.0 x 10.0

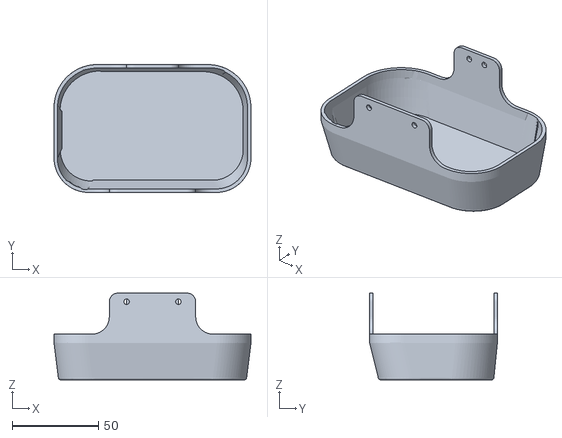
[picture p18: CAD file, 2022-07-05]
design/STL/Shell/Front_Shell.stl
114.0 x 74.0 x 50.3

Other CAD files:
Simulation/URDF/rf shoulder.obj
simulation/meshes/lb_shoulder.obj
Simulation/URDF/rb shoulder.obj
design/STL/Frame/Right_Servo_Mount.stl
simulation/meshes/rb_shoulder.obj
Simulation/URDF/lb shoulder.obj
Simulation/URDF/lf shoulder.obj
design/STL/Frame/Electronics_Mounting_Plate.stl
design/STL/Frame/Inner_Shoulder_Frame.stl
design/STL/Frame/Lower_Shoulder_Frame.stl
design/STL/Frame/Side_Body_Beam.stl
design/STL/Frame/Upper_Shoulder_Frame.stl
design/STL/Legs/Femur.stl
design/STL/Legs/Femur_Servo_Connector.stl
design/STL/Legs/Right_Shoulder.stl
design/STL/Legs/Short_Link.stl
simulation/meshes/femur.obj
simulation/meshes/frame.obj
simulation/meshes/lf_shoulder.obj
simulation/meshes/shell.obj
simulation/meshes/tibia.obj

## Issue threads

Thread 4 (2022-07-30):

Lower Shoulder Frame stl missing

benbigbeard, 2022-07-30:
Hey, Lower Shoulder Frame stl file is missing from the design dir

Great work and design by the way!

Jerome-Graves, 2022-07-30:
[https://github.com/Jerome-Graves/yertle/commit/cff3215dc4ab797bc5a6a6b08cb38be7792e91ae](fixed)

Closed 2022-07-30.

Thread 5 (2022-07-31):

Left/Right Shoulders different

evanwyatt, 2022-07-31:
It looks like the left and right shoulder STLs are different designs, the left shoulder looks to be an older design? The right shoulder matches the CAD.

Are you able to confirm the left shoulder should just be mirror of the right shoulder?

Jerome-Graves, 2022-07-31:
Thanks, I've accidentally added the bearing to the stl file. I will fix this now

Jerome-Graves, 2022-07-31:
[https://github.com/Jerome-Graves/yertle/commit/4d145622e7d98a33851c681c44f7bdecb39f5b37](fixed)

evanwyatt, 2022-07-31:
Thanks, I thought it looked like a bearing!

Closed 2022-07-31.

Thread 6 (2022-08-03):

BOM Bearing not correct

WalterWampe, 2022-08-03:
Hey there,

I was ordering the bearings according to the BOM, but found that one type is incorrect.

> RS PRO Miniature Ball Bearing -3x10X4mm O.D    x8

In the CAD you used 3x13x5.

Thanks for the work!

Jerome-Graves, 2022-08-03:
Thanks! I have updated this.

Closed 2022-08-03.

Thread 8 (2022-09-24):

Some 3D parts need support

pmoliterni, 2022-09-24:
As is written on the website, is it possible to print the 3D parts without any support. I've tried to find a solution with no support with all the possible positions but some files require support (i.e. Inner/Outer Tibia).

Jerome-Graves, 2022-09-27:
Thanks for spotting the error. This is a mistake. Most of the parts can be built without supports (all of the frame parts). But not all.

Closed 2022-09-27.

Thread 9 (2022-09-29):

Outer Shoulder Frame probably contains bearings

pmoliterni, 2022-09-29:
The STL file "Outer Shoulder Frame" probably contains bearings. Is it that correct ?

Jerome-Graves, 2022-09-30:
Yes, I will fix this now.

Jerome-Graves, 2022-10-04:
#

Jerome-Graves, 2022-10-04:
> The STL file "Outer Shoulder Frame" probably contains bearings. Is it that correct ?

This was an error, and I have removed the bearings from the file.

Closed 2022-10-04.

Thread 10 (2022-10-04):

Wrong number bushing bearings in BOM -  should be 32

Jerome-Graves, 2022-10-04:
Mistake in the number of bushing bearings required. It should be 32.

Closed 2022-10-04.

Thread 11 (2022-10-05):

Inner and Outer Tibia

pmoliterni, 2022-10-05:
In the README is suggested to print "4 Inner Tibia" and "4 Outer Tibia" but they differs from the right leg to the left one as also depicted in the the SPEP file. All the "Inner Tibia" should contain the seat for the bolt but if you print the STL as suggested in the README the right leg will contain the seat for the bolt in the outer Tibia.

Because the STEP file already contains all the file needs should be nice to print 2 Inner Tibia for the Right Leg, 2 Inner Tibia for the Left Leg, 2 Outer Tibia for the Right Leg and 2 Outer Tibia for the Left Leg. I hope I was clear enough.

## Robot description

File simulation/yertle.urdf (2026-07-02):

<?xml version="1.0"?>
<robot name="Dog">
	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
	<link name="base_link">
		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
		<inertial>
			<mass value="1.5" />
			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
		</inertial>
	</link>
	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
	<link name="frame">
		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
		<inertial>
			<mass value="0.025" />
			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
		</inertial>
		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
	</link>
	<joint name="base_to_frame" type="fixed">
		<parent link="base_link" />
		<child link="frame" />
		<origin xyz="0 0 0" />
	</joint>
	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
	<link name="lf_shoulder">
		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
		<inertial>
			<mass value="0.025" />
			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
		</inertial>
	</link>
	<joint name="lf_shoulder" type="revolute">
		<parent link="base_link" />
		<child link="lf_shoulder" />
		<origin xyz="0.090 0.037 0" />
		<axis xyz="1 0 0" />
		<limit lower="-0.7854" upper="0.7854" effort="3.0" velocity="10.0" />
	</joint>
	<link name="lf_thigh">
		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
		<inertial>
			<mass value="0.025" />
			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
		</inertial>
	</link>
	<joint name="lf_thigh" type="revolute">
		<parent link="lf_shoulder" />
		<child link="lf_thigh" />
		<origin xyz="0.025 0.027 0 " />
		<axis xyz="0 1 0" />
		<limit lower="-1.5708" upper="0.3491" effort="3.0" velocity="10.0" />
	</joint>
	<link name="lf_shin">
		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
		<inertial>
			<mass value="0.025" />
			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
		</inertial>
		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
	</link>
	<joint name="lf_shin" type="revolute">
		<parent link="lf_thigh" />
		<child link="lf_shin" />
		<origin xyz="0 0 -0.130 " />
		<axis xyz="0 1 0" />
		<limit lower="0.2269" upper="1.5708" effort="3.0" velocity="10.0" />
	</joint>
	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
	<link name="rf_shoulder">
		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
		<inertial>
			<mass value="0.025" />
			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
		</inertial>
	</link>
	<joint name="rf_shoulder" type="revolute">
		<parent link="base_link" />
		<child link="rf_shoulder" />
		<origin xyz="0.090 -0.040 0" />
		<axis xyz="1 0 0" />
		<limit lower="-0.7854" upper="0.7854" effort="3.0" velocity="10.0" />
	</joint>
	<link name="rf_thigh">
		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
		<inertial>
			<mass value="0.025" />
			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
		</inertial>
	</link>
	<joint name="rf_thigh" type="revolute">
		<parent link="rf_shoulder" />
		<child link="rf_thigh" />
		<origin xyz="0.025 -0.027 0 " />
		<axis xyz="0 1 0" />
		<limit lower="-1.5708" upper="0.3491" effort="3.0" velocity="10.0" />
	</joint>
	<link name="rf_shin">
		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
		<inertial>
			<mass value="0.025" />
			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
		</inertial>
		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
	</link>
	<joint name="rf_shin" type="revolute">
		<parent link="rf_thigh" />
		<child link="rf_shin" />
		<origin xyz="0 0 -0.130 " />
		<axis xyz="0 1 0" />
		<limit lower="0.2269" upper="1.5708" effort="3.0" velocity="10.0" />
	</joint>
	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
	<link name="lb_shoulder">
		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
		<inertial>
			<mass value="0.025" />
			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
		</inertial>
	</link>
	<joint name="lb_shoulder" type="revolute">
		<parent link="base_link" />
		<child link="lb_shoulder" />
		<origin xyz="-0.081 0.038 0" />
		<axis xyz="1 0 0" />
		<limit lower="-0.7854" upper="0.7854" effort="3.0" velocity="10.0" />
	</joint>
	<link name="lb_thigh">
		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
		<inertial>
			<mass value="0.025" />
			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
		</inertial>
	</link>
	<joint name="lb_thigh" type="revolute">
		<parent link="lb_shoulder" />
		<child link="lb_thigh" />
		<origin xyz="-0.043 0.027 0 " />
		<axis xyz="0 1 0" />
		<limit lower="-1.5708" upper="0.3491" effort="3.0" velocity="10.0" />
	</joint>
	<link name="lb_shin">
		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
		<inertial>
			<mass value="0.025" />
			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
		</inertial>
		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
	</link>
	<joint name="lb_shin" type="revolute">
		<parent link="lb_thigh" />
		<child link="lb_shin" />
		<origin xyz="0 0 -0.130 " />
		<axis xyz="0 1 0" />
		<limit lower="0.2269" upper="1.5708" effort="3.0" velocity="10.0" />
	</joint>
	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
	<link name="rb_shoulder">
		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
		<inertial>
			<mass value="0.025" />
			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
		</inertial>
	</link>
	<joint name="rb_shoulder" type="revolute">
		<parent link="base_link" />
		<child link="rb_shoulder" />
		<origin xyz="-0.081 -0.040 0" />
		<axis xyz="1 0 0" />
		<limit lower="-0.7854" upper="0.7854" effort="3.0" velocity="10.0" />
	</joint>
	<link name="rb_thigh">
		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
		<inertial>
			<mass value="0.025" />
			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
		</inertial>
	</link>
	<joint name="rb_thigh" type="revolute">
		<parent link="rb_shoulder" />
		<child link="rb_thigh" />
		<origin xyz="-0.043 -0.027 0 " />
		<axis xyz="0 1 0" />
		<limit lower="-1.5708" upper="0.3491" effort="3.0" velocity="10.0" />
	</joint>
	<link name="rb_shin">
		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
		<inertial>
			<mass value="0.025" />
			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
		</inertial>
		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
	</link>
	<joint name="rb_shin" type="revolute">
		<parent link="rb_thigh" />
		<child link="rb_shin" />
		<origin xyz="0 0 -0.130 " />
		<axis xyz="0 1 0" />
		<limit lower="0.2269" upper="1.5708" effort="3.0" velocity="10.0" />
	</joint>
</robot>

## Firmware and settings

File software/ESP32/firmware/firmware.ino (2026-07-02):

/*
* Yertle Quadruped Robot - Firmware for ESP32
* 
* Written by Jerome Graves
* 2022
* Jeromegraves.com    
*/
#include "yertle_lib.h"
#include <Wire.h>

TaskHandle_t Task1;
TaskHandle_t Task2;

ServoClass Servos;
CommClass Comms;
SensorClass Sensors;



const TickType_t hardwareDelay = 10 / portTICK_PERIOD_MS;
const TickType_t commDelay = 10 / portTICK_PERIOD_MS;

void setup() {
  Serial.begin(115200);
  Serial.setTimeout(10);
  
  Wire.setClock(1000000);
  Wire.begin();
  delay(500);

  xTaskCreatePinnedToCore(hardwareTask, "Task1",5000,NULL,2, &Task1,1);
  delay(500);

  xTaskCreatePinnedToCore(commTask, "Task2",5000,NULL,1, &Task2, 0);
  delay(500);
}

// Task pinned to core 1: I2C, servos and sensors.

void hardwareTask(void* parameter) {
  Serial.print("\nHardwareTask is running on core ");
  Serial.println(xPortGetCoreID());

  Sensors.start();
  Servos.start();
  Servos.tick();
  
  for (;;) {
    Servos.tick();
    Sensors.tick();
    vTaskDelay(hardwareDelay);
  }
}


// Task pinned to core 0: WiFi and serial communication.
void commTask(void* parameter) {
  Serial.print("\ncommTask is running on core ");
  Serial.println(xPortGetCoreID());
  Comms.start();
  for (;;) {
    Comms.listen();
    vTaskDelay(commDelay);
  }
}

void loop(){};

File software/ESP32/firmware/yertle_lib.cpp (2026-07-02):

#include <Wire.h>
#include "yertle_lib.h"
#include <Arduino.h>
#include <FaBoPWM_PCA9685.h>
#include "WiFi.h"
#include "AsyncUDP.h"
#include <MPU9250.h>

MPU9250 mpu;

FaBoPWM ServoDriver;

AsyncUDP udpClient;
AsyncUDP udpServer;


PoseAngle currentPoseAngle, defaultPoseAngle;
PoseCartesian poseCartesian;

ImuConfig imuConfig;
ImuData imuData;

Flags flag;
String InputDataString;


// WiFi settings; change to match your network.
const char* ssid = "dog-net";
const char* password = "dognet123";

unsigned int localUdpPort = 1234;  //  port to listen on

IPAddress local_IP(10, 0, 0, 88);

// Set your Gateway IP address
IPAddress gateway(10, 0, 0, 1);






ServoClass::ServoClass() {
  // NOTHING
}

void ServoClass::start() {  // Start the servo driver
  if (ServoDriver.begin()) {
    ServoDriver.init(200);
    //Serial.println("  Configured FaBo ServoDriver I2C Brick");  // <--  bug with laptop library (int casting to byte?)
  } else {
    //Serial.println("  FaBo 9Axis I2C Brick failed.");
  }
  ServoDriver.set_hz(200);  // <--  bug with laptop library (int casting to byte?)
  //flag.killServosFlag = true;
  
  flag.newPoseCartesianFlag = true;
}

/// set robot to pose

void ServoClass::moveToPose() {
  setAngle(servoId.lf_theta1, currentPoseAngle.lf_theta1, defaultDirection.lf_theta1, defaultLimits.lowerTheta1, defaultLimits.upperTheta1, servoOffsets.lf_theta1);
  setAngle(servoId.lf_theta2, currentPoseAngle.lf_theta2, defaultDirection.lf_theta2, defaultLimits.lowerTheta2, defaultLimits.upperTheta2, servoOffsets.lf_theta2);
  setAngle(servoId.lf_theta3, currentPoseAngle.lf_theta3, defaultDirection.lf_theta3, defaultLimits.lowerTheta3, defaultLimits.upperTheta3, servoOffsets.lf_theta3);
  setAngle(servoId.rf_theta1, currentPoseAngle.rf_theta1, defaultDirection.rf_theta1, defaultLimits.lowerTheta1, defaultLimits.upperTheta1, servoOffsets.rf_theta1);
  setAngle(servoId.rf_theta2, currentPoseAngle.rf_theta2, defaultDirection.rf_theta2, defaultLimits.lowerTheta2, defaultLimits.upperTheta2, servoOffsets.rf_theta2);
  setAngle(servoId.rf_theta3, currentPoseAngle.rf_theta3, defaultDirection.rf_theta3, defaultLimits.lowerTheta3, defaultLimits.upperTheta3, servoOffsets.rf_theta3);
  setAngle(servoId.lb_theta1, currentPoseAngle.lb_theta1, defaultDirection.lb_theta1, defaultLimits.lowerTheta1, defaultLimits.upperTheta1, servoOffsets.lb_theta1);
  setAngle(servoId.lb_theta2, currentPoseAngle.lb_theta2, defaultDirection.lb_theta2, defaultLimits.lowerTheta2, defaultLimits.upperTheta2, servoOffsets.lb_theta2);
  setAngle(servoId.lb_theta3, currentPoseAngle.lb_theta3, defaultDirection.lb_theta3, defaultLimits.lowerTheta3, defaultLimits.upperTheta3, servoOffsets.lb_theta3);
  setAngle(servoId.rb_theta1, currentPoseAngle.rb_theta1, defaultDirection.rb_theta1, defaultLimits.lowerTheta1, defaultLimits.upperTheta1, servoOffsets.rb_theta1);
  setAngle(servoId.rb_theta2, currentPoseAngle.rb_theta2, defaultDirection.rb_theta2, defaultLimits.lowerTheta2, defaultLimits.upperTheta2, servoOffsets.rb_theta2);
  setAngle(servoId.rb_theta3, currentPoseAngle.rb_theta3, defaultDirection.rb_theta3, defaultLimits.lowerTheta3, defaultLimits.upperTheta3, servoOffsets.rb_theta3);
}

// Convert float angle to pwm, needs the forward direction of the servo.
int ServoClass::angleToPWM(bool direction, float input) {
  if (direction == true) return map(input, -90, 90, 400, 2000);
  else if (direction == false)
    return map(input, -90, 90, 2000, 400);
};

// Keeps angle between upper and lower limits.
float ServoClass::filterLimits(float inputValue, float lowerLimit, float upperLimit) {
  if (inputValue < lowerLimit) return lowerLimit;
  else if (inputValue > upperLimit)
    return upperLimit;
  else
    return inputValue;
};

// Set servo angle.
void ServoClass::setAngle(int id, float angle, bool direction, float lowerLimit, float upperLimit, float offset) {

  ServoDriver.set_channel_value(id, int(offset) + angleToPWM(direction, +filterLimits(angle, lowerLimit, upperLimit)));
}

// Disable servos. <- not working
void ServoClass::killServos() {
  ServoDriver.set_channel_value(servoId.lf_theta1, 0);
  ServoDriver.set_channel_value(servoId.lf_theta2, 0);
  ServoDriver.set_channel_value(servoId.lf_theta3, 0);
  ServoDriver.set_channel_value(servoId.rf_theta1, 0);
  ServoDriver.set_channel_value(servoId.rf_theta2, 0);
  ServoDriver.set_channel_value(servoId.rf_theta3, 0);
  ServoDriver.set_channel_value(servoId.lb_theta1, 0);
  ServoDriver.set_channel_value(servoId.lb_theta2, 0);
  ServoDriver.set_channel_value(servoId.lb_theta3, 0);
  ServoDriver.set_channel_value(servoId.rb_theta1, 0);
  ServoDriver.set_channel_value(servoId.rb_theta2, 0);
  ServoDriver.set_channel_value(servoId.rb_theta3, 0);
}
// Send current position PWM data through the serial port (used for zeroing servos).
void ServoClass::sendPWMData() {
  String val[12];
  val[0] = ServoDriver.get_channel_value(servoId.lf_theta1);
  val[1] = ServoDriver.get_channel_value(servoId.lf_theta2);
  val[2] = ServoDriver.get_channel_value(servoId.lf_theta3);
  val[3] = ServoDriver.get_channel_value(servoId.rf_theta1);
  val[4] = ServoDriver.get_channel_value(servoId.rf_theta2);
  val[5] = ServoDriver.get_channel_value(servoId.rf_theta3);
  val[6] = ServoDriver.get_channel_value(servoId.lb_theta1);
  val[7] = ServoDriver.get_channel_value(servoId.lb_theta2);
  val[8] = ServoDriver.get_channel_value(servoId.lb_theta3);
  val[9] = ServoDriver.get_channel_value(servoId.rb_theta1);
  val[10] = ServoDriver.get_channel_value(servoId.rb_theta2);
  val[11] = ServoDriver.get_channel_value(servoId.rb_theta3);
  Serial.print("PWM values: " + val[0] + " " + val[1] + " " + val[2] + " " + val[3] + " " + val[4] + " " + val[5] + " " + val[6] + " " + val[7] + " " + val[8] + " " + val[9] + " " + val[10] + " " + val[11]);
}

// Update function for the servos.
void ServoClass::tick() {
  if (flag.newPoseAngleFlag) {  // <--- switched on in ROS task (extenally)
    moveToPose();
    flag.newPoseAngleFlag = false;
  }

  if (flag.killServosFlag) {
    killServos();
    flag.killServosFlag = false;
  }
  if (flag.newPoseCartesianFlag) {
    solveIk();
    moveToPose();
    flag.newPoseCartesianFlag = false;
  }
  if (flag.sendPWMDataFlag) {
    sendPWMData();
    flag.sendPWMDataFlag = false;
  }
}
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

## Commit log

2022-07-05 read me update
    [Back Shell.stl, Bottom Shell.stl, Bottom Shoulder Frame.stl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]
2022-07-05 updated path
    [Back Shell.stl, Bottom Shell.stl, Bottom Shoulder Frame.stl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]
2022-07-05 update rm
    [Electronics Mounting Plate.stl]
2022-07-16 updated servo centres
2022-07-30 Update README.md
    Added sleeve bearing to BOM for linkages
2022-07-30 Added URDF File
    Added URDF file for pyBullet simulation
    [femur.obj, frame.obj, lb shoulder.obj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]
2022-07-30 Update config.ini
    Updated PID values Still need tuning.
2022-07-30 Update yertle lib.cpp
    Updated servo driver PWM frequency
2022-07-30 Update yertle lib.h
    Updated servo offsets, this need to be moved to config.ini
2022-07-30 Fixed missing lower Shoulder frame
    Renamed file from 'Bottom Shoulder' frame to 'Lower Shoulder frame'.
    [Lower Shoulder Frame.stl]
2022-07-31 Update Left Shoulder.stl
    Fixed left shoulder. no longer has Bearing
    [Left Shoulder.stl]
2022-08-03 Incorrect bearing fixed
    Incorrect Bearing fixed
2022-08-28 Incorrect File
    [Servo Mount Top Bracket.stl]
2022-08-28 Corrected File
    [Left Servo Mount.stl]
2022-09-27 Removed unused variables and Libraries
    Fixed formatting.
    Removed unused variables and Libraries.
    [YertleUI.py, firmware.ino, yertle lib.cpp]
2022-10-04 Delete Yertle Single v2.iges
    .iges file not working. Just the .step and .stl files should be fine.
2022-10-04 Update README.md
    I Fixed sleeve bearing amount. The number should be 32
2022-10-04 Update Outer Shoulder Frame.stl
    Removed bearing from file.
    [Outer Shoulder Frame.stl]
2026-07-01 Modernize repo: hygiene, cross-platform paths, packaging, docs
    - Add proper .gitignore; remove committed orphan .pyc artifact
    - Add requirements.txt and pyproject.toml (no dependency manifest existed)
    - YertleUI.py: resolve config/URDF paths via pathlib (cross-platform, run from any cwd); replace bare assert with clear FileNotFoundError
    - yertle.URDF: fix 19 mesh paths to be relative to the URDF file and use forward slashes
    - Rename 'yertle lib.{h,cpp}' to yertle_lib.{h,cpp} and update includes; fix EPS32 typo
    - README: add repository structure and getting-started sections; fix WiFi password and file-location errors
    [yertle.URDF]
2026-07-01 Add reinforcement-learning locomotion pipeline (learning/)
    - YertleEnv: Gymnasium environment wrapping yertle.URDF in PyBullet
    - sanitizes the URDF's invalid inertia tensors into a trainable model
    - position-control actions as residuals around a standing pose
    - domain randomization (base mass, foot friction, obs noise, pushes)
    - train.py: PPO training via stable-baselines3 (optional TensorBoard)
    - enjoy.py: load and roll out / render a trained policy
    - smoke_test.py: fast env check with no RL dependencies
    - requirements-rl.txt and learning/README.md
    - README: surface learned-locomotion section and updated roadmap
2026-07-01 Add sim-to-real deploy bridge and ROS 2 package
    - learning/deploy.py: run a trained policy on the robot
    - ObservationBuilder + PolicyController mirror YertleEnv exactly
    - firmware 'a' joint-command encoder with calibratable joint mapping
    - SimRobotInterface (PyBullet closed loop) and UdpRobotInterface (ESP32)
    - self-check validates obs shape, command round-trip and upright stance
    - ros2/yertle_rl: ament_python package; policy_node subscribes cmd_vel + imu,
    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
2026-07-01 Tune locomotion reward to induce walking, not standing
    The initial reward let the policy maximise return by standing still
    (high alive/stability terms, a too-forgiving velocity kernel, and a
    command range that included near-zero speeds). Rework it to reward
    motion:
    - add a direct forward-progress term (velocity projected on the command)
    - sharpen the tracking kernel (0.25 -> 0.1)
    - require a meaningful commanded speed (0.15-0.35 m/s)
    - reduce alive/energy/height weights so moving beats standing
2026-07-01 Fix robot model: valid inertia tensors, no-space mesh filenames
    - Replace the URDF's invalid inertia tensors (zeros on base, off-diagonal
    equal to diagonal on legs) with valid mass-scaled diagonal tensors; PhysX
    rejects the originals for articulations
    - Rename the four 'x shoulder' mesh files to 'x_shoulder' and fix mtllib refs;
    spaces are illegal in USD prim paths
    - gitignore generated Simulation/usd/ and isaac_lab/runs/
    [lb_shoulder.obj, lf_shoulder.obj, rb_shoulder.obj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]
2026-07-01 Add NVIDIA Isaac Lab GPU locomotion pipeline (isaac_lab/)
    - YERTLE_CFG articulation from the converted USD, leg actuators
    - Flat velocity-tracking env inheriting Isaac Lab's locomotion task, remapped
    to Yertle's bodies (base_link, feet=*_shin)
    - rsl_rl PPO config; train.py and play.py (Windows DLL-order fixes: import
    torch/rsl_rl/h5py before launching Kit)
    - Trained on RTX 4070: 4096 parallel envs, reward 0->40, episode length
    1000/1000; reward curve and demo GIF in isaac_lab/media
2026-07-01 PyBullet RL: actuator/reward tuning, video and reward-curve tooling
    - Stronger actuators and reworked reward (forward-progress term, no free
    standing bonus) plus PPO entropy for exploration
    - record_video.py and plot_progress.py for demo artifacts; fix render() dtype
    - Update requirements-rl and README
2026-07-01 ros2: document that the node builds and runs (ROS 2 Humble via RoboStack)
    The package was previously written but unrun. It now builds with colcon and the
    node runs live (cmd_vel + imu -> joint_commands), validated on Windows via
    RoboStack. Add the RoboStack quickstart and note PYTHONPATH for the learning import.
2026-07-02 Add firmware joint limits and actuator caps to the simulation model
    - URDF: 12 leg joints continuous -> revolute with firmware-derived limits
    (shoulder +/-45deg, thigh -90..20deg, shin 13..90deg), effort 3 N.m,
    velocity 10 rad/s; PhysX now enforces them as hard constraints
    - Keep the implicit PhysX drive with effort/velocity caps: an explicit
    DC-motor model was tried and is underdamped at hobby-servo gains (the
    robot oscillates against its limits and cannot hold stance); reasoning
    documented in yertle_cfg.py
    - Flat-task reward: gentle smoothness shaping (action rate, body wobble,
    joint-limit proximity) tuned so per-step reward of useful behavior stays
    positive; heavier penaltie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
    [yertle.URDF]
2026-07-02 Add teacher-student distillation to a deployable policy
    Student observation group drops the privileged base linear velocity (and
    height scan); the trained flat PPO policy is loaded as a frozen teacher.
    Student matches the teacher (mean reward 40.4 vs 40.5, imitation loss ~1e-3),
    so the deployed controller needs only measurable signals.
2026-07-02 ROS 2: closed-loop walking demo and bidirectional Isaac Sim bridge
    - demo_ros2_loop.py: full control loop over live topics (sim node publishes
    joint_states/imu and applies joint_commands; policy node tracks cmd_vel);
    the trained policy walks ~0.5 m in 8 s
    - ros2_bridge.py: Isaac Sim exposed on ROS 2 via the isaacsim.ros2.bridge
    OmniGraph extension; verified bidirectionally from a separate RoboStack
    ROS 2 install (12 joints on /joint_states; /joint_command moves the robot)
    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
2026-07-02 Docs: bring every README up to date with the current state
    - Root: Isaac Lab section covers rough terrain and distillation with current
    commands; repo structure adds paper/ and media/; link the technical report;
    To Do reduced to what actually remains (hardware deployment, actuator ID);
    software section describes host/robot roles and links the ROS 2 work; drop
    the stale (WIP) and (todo) markers
    - isaac_lab: file listing includes rough/distill/bridge; train/play examples
    use --task and plain-script invocation; distillation and bridge sections;
    stale 'no joint limits' note replaced with the current model state and the
    zero-action sanity check; no hardcoded user paths
    - learning: s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
2026-07-02 Restructure: consistent lowercase layout, snake_case filenames, code polish
    Naming was split between the 2022 layout (Design/, Simulation/, Software/,
    CamelCase and spaced filenames) and the newer lowercase packages. Unify:
    - Design/ -> design/, Simulation/ -> simulation/, Software/ -> software/
    - Simulation/yertle.URDF -> simulation/yertle.urdf
    - Simulation/URDF/ (meshes) -> simulation/meshes/ (paths inside the URDF
    updated to match)
    - Software/YertleUI/YertleUI.py -> software/yertle_ui/yertle_ui.py
    - design STL/CAD files: spaces -> underscores (also fixes a double-space
    filename); all bill-of-materials links updated
    - every path reference updated (env URDF path, Isaac USD path, bridge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
    [Back_Shell.stl, Bottom_Shell.stl, Electronics_Mounting_Plate.stl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]
